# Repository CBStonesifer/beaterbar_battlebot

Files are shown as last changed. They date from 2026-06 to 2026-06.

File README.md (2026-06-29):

# Beater-Bar BattleBot

A 3-pound (beetleweight) combat robot designed and built across the full hardware stack: mechanical CAD, PCB layout, and embedded firmware. The goal was a **reproducible end-to-end build process** — from CAD model to fabricated board to driving firmware — rather than peak performance. V2 will optimize for weight and combat performance.

> A full reflection on the build is on Substack: [Earning Three Minutes in the Ring](https://open.substack.com/pub/carterstonesifer/p/earning-three-minutes-in-the-ring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)

**Skills demonstrated:** Fusion 360 / FDM prototyping · KiCad schematic + layout · custom footprint creation · Gerber fabrication output · ESP32 embedded C · RC PWM decode · LEDC motor PWM · skid-steer mixing

---

## Repo Structure

```
cad/          — 3D-printable chassis, wheels, and weapon (STL + 3MF)
pcb/          — KiCad schematic, layout, custom footprints, and gerbers
firmware/     — Arduino sketch for ESP32 (RC decode + motor mixing)
```

---

## Design Decisions

- **Beater bar weapon** — a relatively simple and proven design with high impact potential in the arena. The main weakness is being flipped; a lower profile in V2 addresses this directly.
- **Unified motor driver (DRV8833)** — the same driver module is used for all three motors (left drive, right drive, weapon). Simplifies the BOM and firmware; the weapon motor runs off its own dedicated DRV8833 instance.
- **Skid-steer drivetrain** — keeps mechanical complexity low while maintaining full mobility. No steering linkage, no Ackermann geometry, just two independently driven wheels.
- **Belt-driven weapon** — the GT2 20T/60T pulley ratio amplifies the motor's output speed to spin the beater bar faster than a direct-drive setup would allow.
- **Unitary printed body** — a single-piece chassis provides structural strength without mechanical interlocks between parts. Drive and weapon geometry were validated as separate prints first, then merged once the layout was confirmed.

---

## Bill of Materials

| # | Component | Part | Qty | Specs | Link |
|---|---|---|-----|---|---|
| 1 | MCU | ESP32 dev board | 1 | Dual-core 32-bit, 240 MHz, 3.3V, WiFi + BT | [Amazon](https://www.amazon.com/dp/B0C9TGJRPH) |
| 2 | Motor driver | DRV8833 | 3 | 1.5 A continuous, 2 A peak | [Amazon](https://www.amazon.com/dp/B0DXF6LZB1) |
| 3 | Buck regulator | LM2596 | 1 | 3–40V in, 1.5–35V adj out | [Amazon](https://www.amazon.com/dp/B0DBVYP91F) |
| 4 | Battery | 2S LiPo | 1 | 7.4V, 2000mAh, T-plug | [Amazon](https://www.amazon.com/dp/B0FCFVWS1K) |
| 5 | RC transmitter + receiver | — | 1 set | PWM out, 2-channel minimum | [Amazon](https://www.amazon.com/dp/B0FJDFJ38M) |
| 6 | Drive motors | 390 brushed | 2 | 6–12V, 6,300 RPM @ 12V, 1A no-load, 2.3mm shaft | [Amazon](https://www.amazon.com/dp/B01M58POHF) |
| 7 | Weapon motor | 550 brushed, 55T | 1 | 7.4V (2S), 36mm dia, 3.17mm shaft | [Amazon](https://www.amazon.com/dp/B0FXG6J3Z9) |
| 8 | Weapon belt drive | GT2 pulley + belt | 1 set | 20T / 60T, 8mm bore, 200mm belt | [Amazon](https://www.amazon.com/dp/B08QZ4365D) |
| 9 | Connectors | JST-XH 3-pin | 10 pairs | 2.54mm pitch, 26AWG, 200mm | [Amazon](https://www.amazon.com/dp/B0D3LVLMP9) |
| 10 | Print filament | PLA-CF 1.75mm | 1 spool | 1kg, carbon-fiber reinforced | [Amazon](https://www.amazon.com/dp/B0D7VV1YC7) |

---

## CAD

**Tool:** Fusion 360 → FDM (PLA-CF)  
**All parts:** `cad/` — available as both `.stl` and `.3mf`

| File | Description |
|---|---|
| `chassis.stl` / `.3mf` | Unitary chassis: electronics bay, drive motor mounts, weapon mount |
| `drive_wheel.stl` / `.3mf` | Drive wheels (print ×2) |
| `weapon_impactor.stl` / `.3mf` | Beater-bar weapon impactor |

Drive and weapon subsystems were first validated as separate prints, then consolidated into a single `chassis` once geometry was confirmed. Total bot target: ≤ 3 lb; drive motors are the dominant mass — body is designed to be as light as possible.

| | |
|---|---|
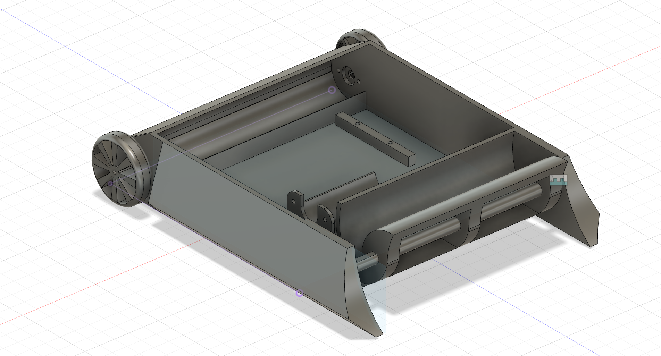
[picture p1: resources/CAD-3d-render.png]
Fusion 360 chassis render
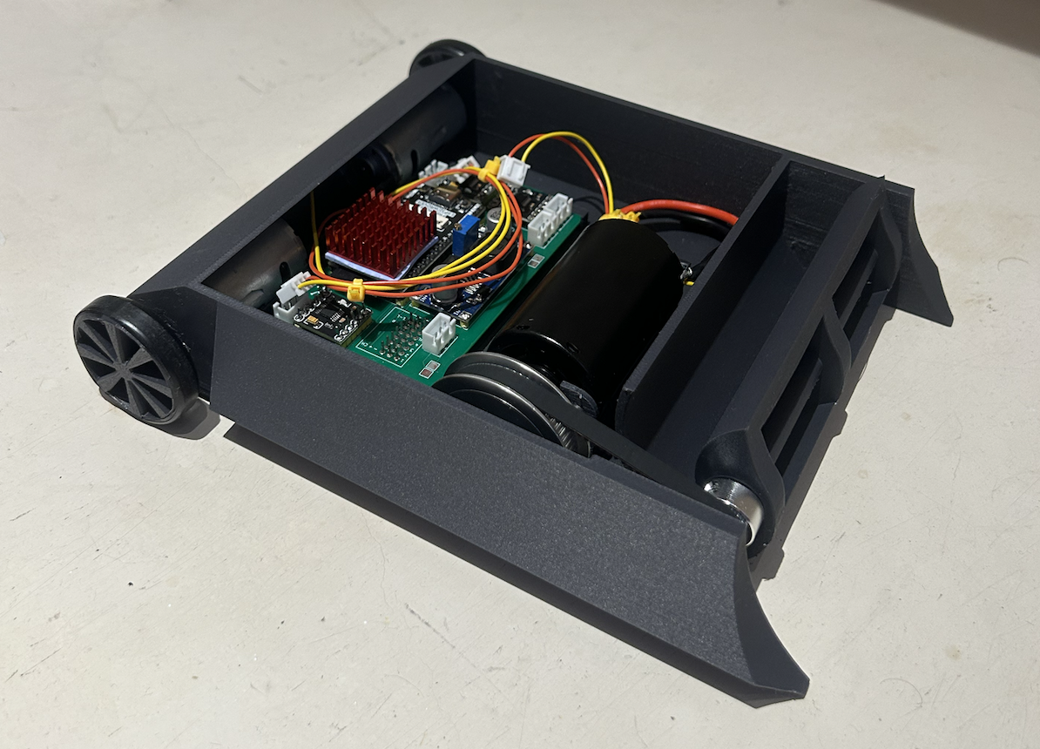
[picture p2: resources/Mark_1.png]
Assembled Mark 1
|  |  |
| *Fusion 360 render — `chassis`* | *Mark 1 assembled — PCB and drive motor installed* |

---

## ECAD

**Tool:** KiCad 7  
**Fabrication output:** `pcb/gerbers/battlebot_gerbers_v1.zip` — ready to send to any fab house

### Files

| File | Purpose |
|---|---|
| `pcb/BattleBot.kicad_sch` | Full schematic |
| `pcb/BattleBot.kicad_pcb` | Board layout |
| `pcb/BattleBot-parts.kicad_sym` | Custom KiCad symbol library |
| `pcb/BattleBot.pretty/` | Custom footprint library (6 footprints) |
| `pcb/gerbers/` | Gerber + drill files |

### Power Architecture

```
LiPo ──→ LM2596 (buck) ──→ 5V ──→ ESP32-WROVER-E
LiPo ──→ DRV8833 (×3) ──→ Drive motors + weapon motor (direct VBAT)
```

### GPIO Pin Assignments

| Signal | ESP32 GPIO |
|---|---|
| RC Steering (PWM in) | 35 |
| RC Throttle (PWM in) | 34 |
| RC Weapon toggle (PWM in) | 18 |
| Left motor IN1 | 25 |
| Left motor IN2 | 26 |
| Right motor IN1 | 27 |
| Right motor IN2 | 14 |
| Weapon motor IN1 | 2 |
| Weapon motor IN2 | 15 |
| UART0 debug | 115200 baud |

### Custom Footprints

All footprints in `pcb/BattleBot.pretty/` were drawn from datasheets:

| Footprint | File |
|---|---|
| ESP32-WROVER-E | `ESP32-WROVER-E.kicad_mod` |
| DRV8833 | `DRV8833.kicad_mod` |
| LM2596 | `LM2596.kicad_mod` |
| RC Receiver | `Receiver.kicad_mod` |
| 3-pin connector | `3Pin-Connector.kicad_mod` |
| Test point pad | `Testpoint-Pad.kicad_mod` |

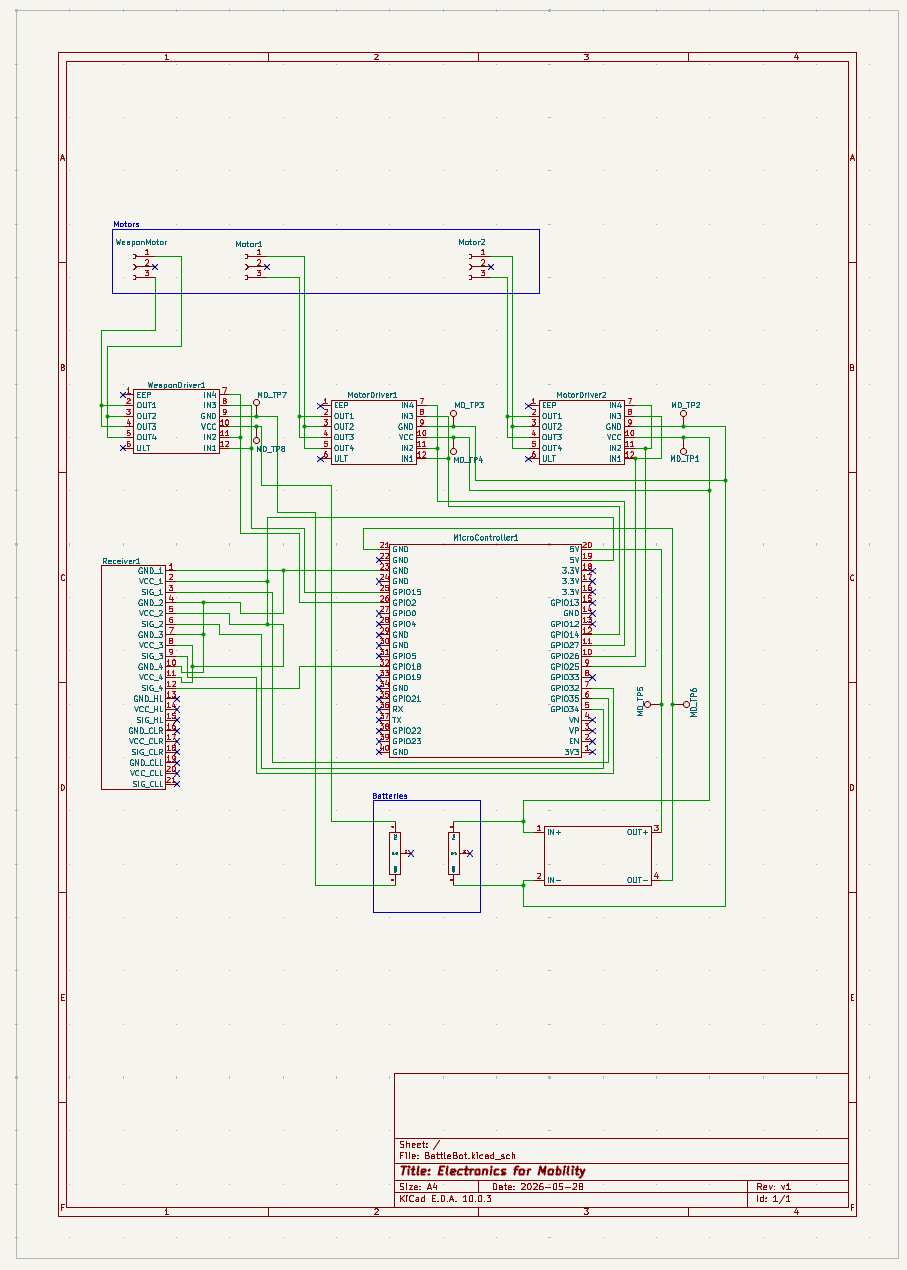
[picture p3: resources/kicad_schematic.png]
KiCad schematic

*Schematic — `BattleBot.kicad_sch`*

| | |
|---|---|
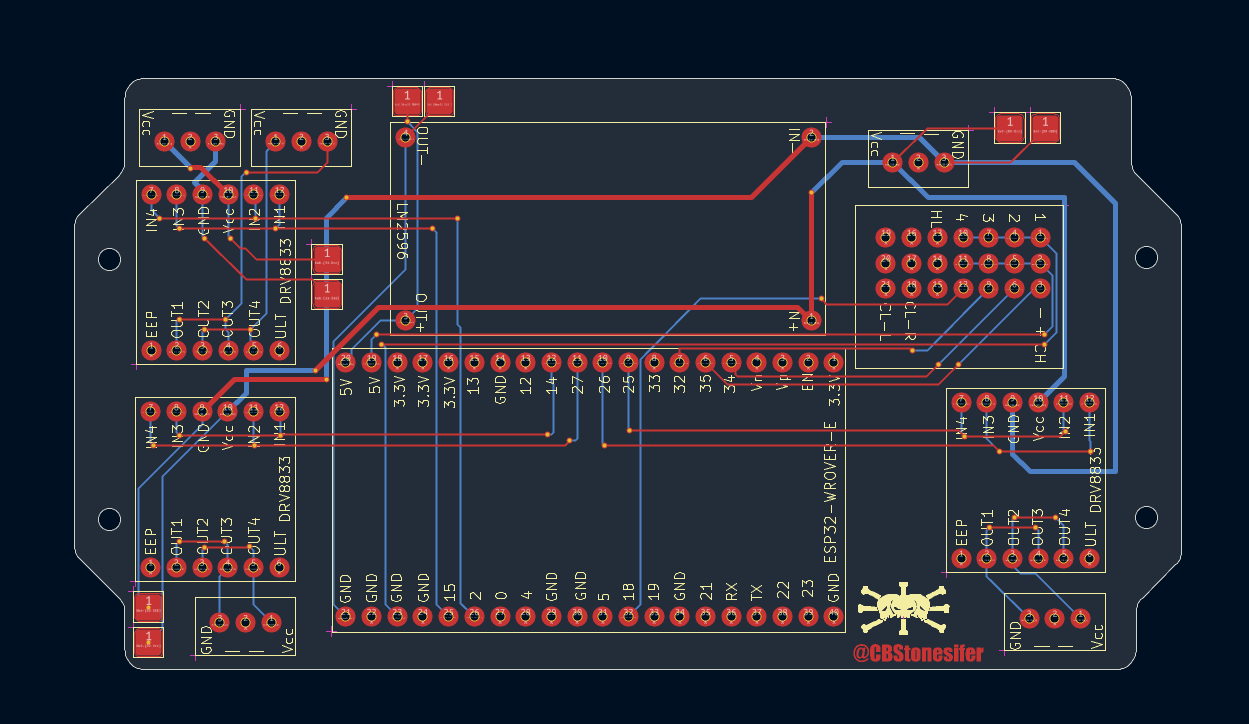
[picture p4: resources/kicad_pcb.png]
KiCad PCB layout
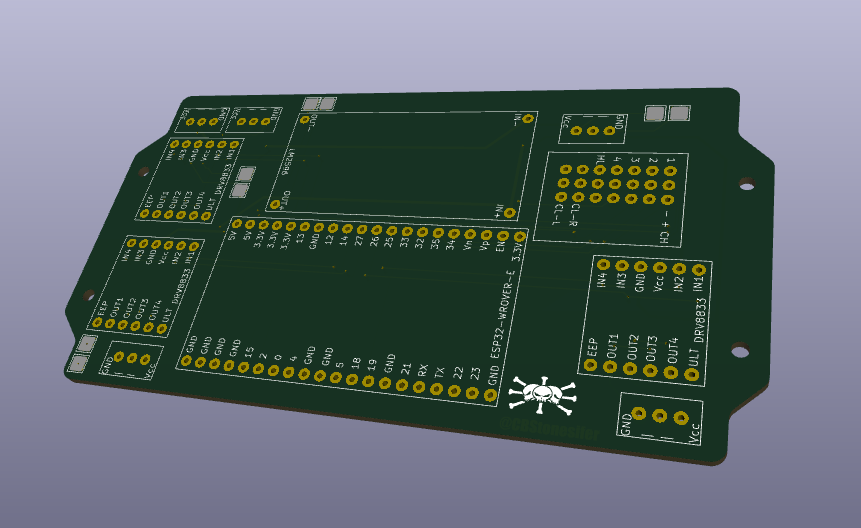
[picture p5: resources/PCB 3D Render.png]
PCB 3D render
|  |  |
| *Layout — `BattleBot.kicad_pcb`* | *KiCad 3D render* |

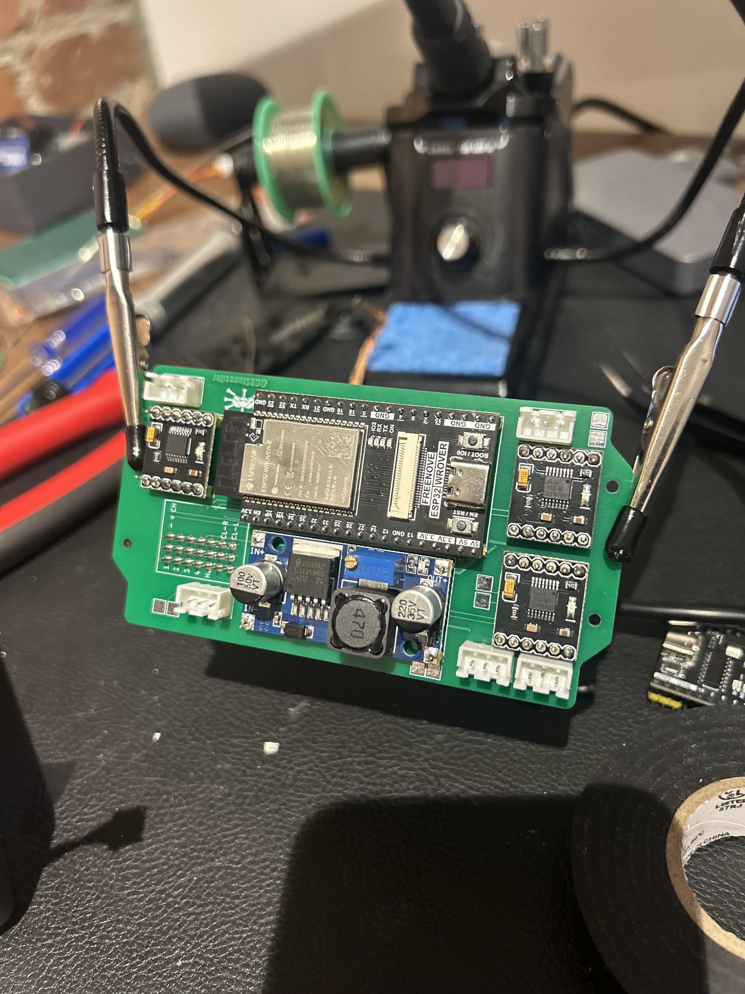
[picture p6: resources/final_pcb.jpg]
Populated PCB

*Fabricated and populated board*

---

## Firmware

**Toolchain:** Arduino IDE + ESP32 board support package  
**Board target:** ESP32 Wrover Module  
**Sketch:** `firmware/signal_driver/signal_driver.ino`

### Control Loop

```
loop()
  ├── pulseIn GPIO 35/34/18  — read steering, throttle, weapon (25ms timeout each)
  ├── failsafe check         — any invalid/missing pulse → stopAll() and skip frame
  ├── steeringFromPulse()    — map to [-100, 100] → deadband
  ├── throttleFromPulse()    — map to [-100, 100] → deadband
  ├── mixAndDrive()          — skid-steer mix → setMotor() → LEDC PWM duty
  └── setWeapon()            — full speed on WEAPON_IN1 when pulse > 1500 µs
```

> **Failsafe:** `pulseIn` returns 0 on timeout, and a valid RC frame sits ~1000–2000 µs. Any pulse outside the 900–2100 µs band is treated as link loss — all drive and weapon output is cut for that loop. Without this guard a lost signal maps to full reverse, so the bot drives off on its own when the transmitter drops.

### Motor Mixing

- **Straight:** `left = right = throttle`
- **Driving turn:** inner wheel = `throttle × (TURN_MIX_RATIO / 100)`
- **Spin-in-place:** `left = +steering`, `right = −steering`

### Calibration Constants

| Constant | V1 Value | Purpose |
|---|---|---|
| `STEERING_MIN` | 965 µs | Min receiver pulse |
| `STEERING_MAX` | 1882 µs | Max receiver pulse |
| `THROTTLE_MIN` | 1055 µs | Min throttle pulse |
| `THROTTLE_IDLE` | 1565 µs | Neutral position |
| `THROTTLE_MAX` | 2000 µs | Max throttle pulse |
| `DEADBAND` | 5 | Noise rejection around neutral |
| `TURN_MIX_RATIO` | 50 | Inner-wheel scaling (0–100) |
| `PWM_FREQ` | 20,000 Hz | LEDC motor PWM frequency |
| `PWM_RES` | 8-bit | Duty cycle range (0–255) |

> These constants are radio-specific. Re-measure pulse widths for your transmitter before first drive.

### Flash Instructions

1. Install ESP32 board support in Arduino IDE
2. Open `firmware/signal_driver/signal_driver.ino`
3. Select **ESP32 Wrover Module**, set the correct COM port
4. Update calibration constants for your RC radio
5. Upload

---

## Testing & Validation

The bot was driven under full battery power with all systems operating independently:

- **Drive** — successfully accelerated, turned, and reversed at varying speeds under RC control.
- **Weapon** — spun up to full speed and was toggled on and off from the transmitter.
- **Carpet performance** — struggled on carpet. The wheels lacked grip, and the design relies on the body sliding along the ground to stay low against opponents — which doesn't work well on high-friction surfaces.
- **Battery connector** — the 3-pin plugs do not physically prevent reverse polarity insertion. Connecting the battery backwards is easy to do and will damage the board.

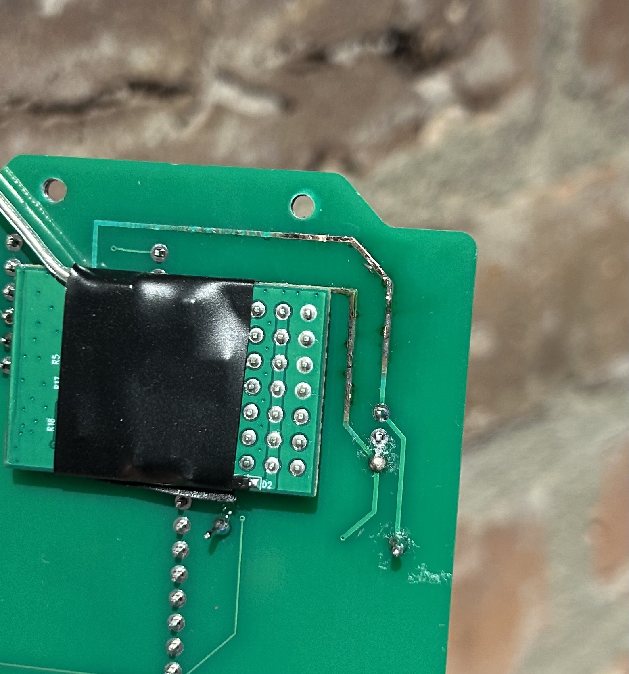
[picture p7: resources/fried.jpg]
Fried ESP32 from reverse polarity

<br><em>ESP32 after a flipping power contacts</em>

---

## Known Issues & Further Improvements (V2)

- **Chassis Side Overhangs** — the overhangs on the side were quickly added to thicken the width of the walls to strengthen the bot, and for style. They provide a grip for another bot to easily flip the vehicle. The next design should minimize the gap between the side edges and the ground.
- **Hard Power Cut-Off** — as per NHRL rules, the bot requires a quick physical power disconnect to disable movement and weapon systems, not just a code deactivation.
- **Reverse-polarity protection** — V1 fried a board because the 3-pin power plug can be inserted backwards. V2 should add a series Schottky / P-channel MOSFET ideal-diode at the battery input *and* a keyed/slotted connector so the battery physically can't seat the wrong way. The board itself is cheap and easily reproducible from the gerbers, so losing one to this wasn't costly — but it's a trivial thing to design out.
- **Undersized motor drivers** — the DRV8833 is rated 1.5 A continuous / 2 A peak, but the 390 drive motors stall around 5–7 A and the 550 weapon motor well above that. Under real load the part is pushed past its peak, where it current-limits or fails. V2 should size the H-bridge to *stall* current, not no-load current, and add a firmware soft-start ramp so the weapon spins up gradually instead of slamming to full duty and drawing a large inrush spike. The broader lesson: parts that work together aren't necessarily matched on performance — each one needs headroom for the worst case the system will actually see.
- **Hardened weapon impactor** — machine or print in PETG/nylon/polycarbonate; evaluate a metal impactor for the beater bar.
- **Weight optimization** — the current design is 2.76 lbs, which leaves room to upgrade/add additional parts (i.e. the weapon material should be metal).
- **Optimize print settings** — a final print with more granular layer heights and higher infill will strengthen the hull.
- **A Roof** — the top of the bot needs a solid roof that could also act as a battery retainer. Batteries are currently loose within the chassis.
- **Sweet Paint Job** — the bot needs some decals and a layer of spray paint to make it look more threatening.
- **Wheel Grips and Covers** — the wheels are exposed and use electrical tape for grip. They must be better protected, as immobility is an immediate loss in the arena. A set of proper tires would help with mobility, and the front shovel can catch on uneven surfaces.
- **Beater Bar orientation is reversed** — the edge of the beater bar faces inward, counter to the direction the bar spins. Opposing robots are hit with the blunt edge of the weapon rather than the sharp, scraping side that should brush close to the ground.
- **Blocking RC read (`pulseIn`)** — the firmware reads each RC channel sequentially using `pulseIn()`, which blocks for up to ~25ms per channel, so a full loop can take ~75ms. Signal loss is now handled (an invalid/missing pulse disarms all motors), but the read is still blocking. V2 should use hardware interrupts or RTOS tasks to read channels concurrently.

---

## Tools Required

- **3D printer** — Bambu A1 (or equivalent FDM printer capable of PLA-CF)
- **Soldering iron** — flux is mandatory; makes the joints significantly cleaner and easier
- **Wire stripper**
- **Extra header pins**
- **Assorted screws and a screwdriver**

---

## Status

| Version | Status | Focus |
|---|---|---|
| V1 | Complete | Cost-optimized, full-stack process established |
| V2 | Planned | Weight/performance, hardened materials, active fault handling |

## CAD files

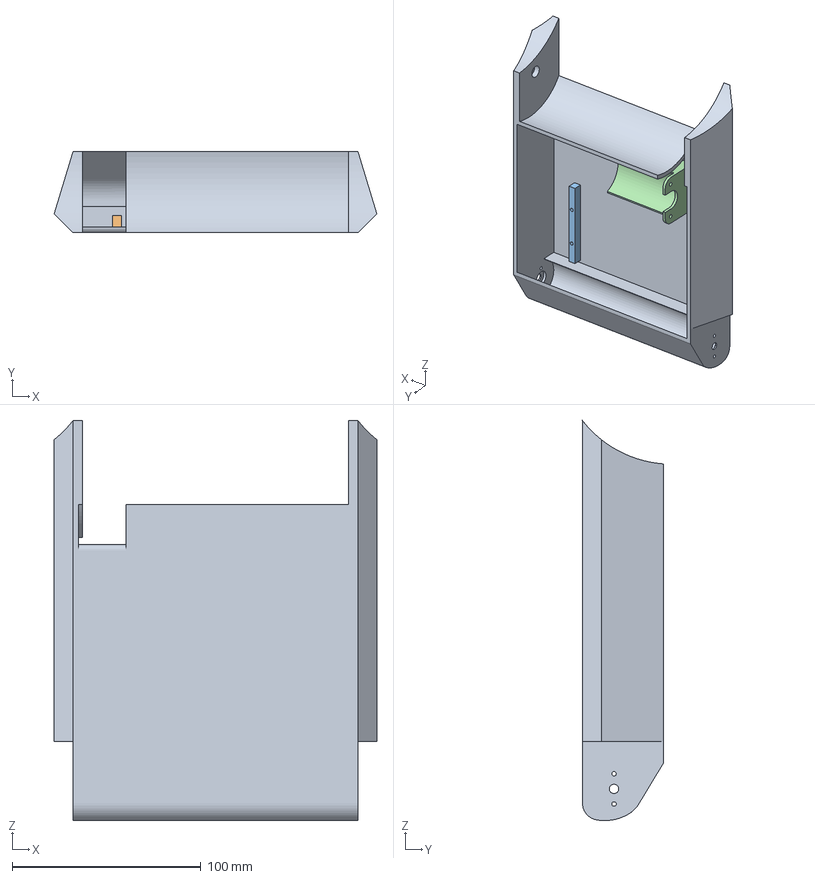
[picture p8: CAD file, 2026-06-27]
cad/chassis.3mf
171.0 x 43.0 x 212.0 mm

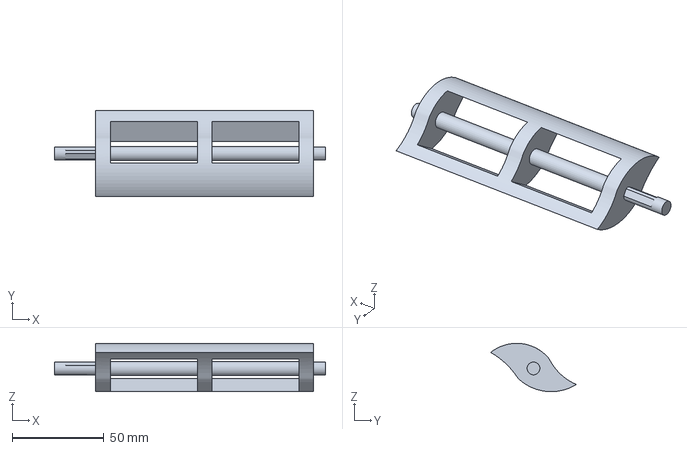
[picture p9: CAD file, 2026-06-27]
cad/weapon_impactor.3mf
148.0 x 46.8 x 26.3 mm

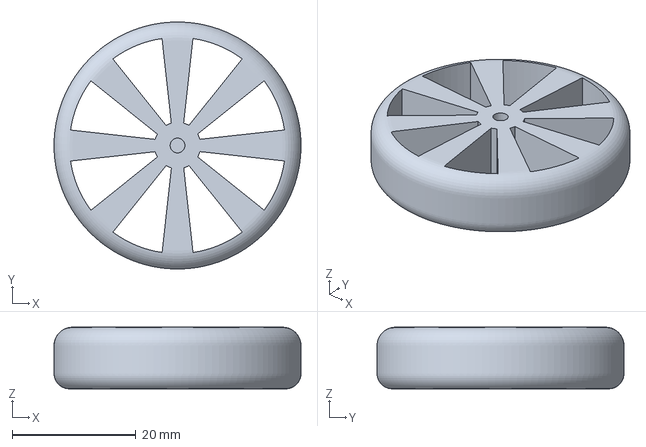
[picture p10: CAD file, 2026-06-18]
cad/drive_wheel.3mf
40.0 x 40.0 x 10.0 mm

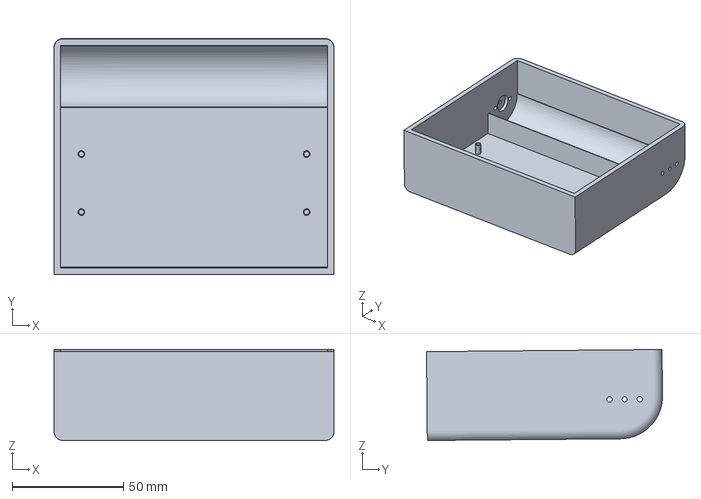
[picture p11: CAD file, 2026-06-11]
cad/haul_v1.3mf
126.0 x 106.2 x 41.0 mm

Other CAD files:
cad/chassis.stl
cad/drive_wheel.stl
cad/weapon_impactor.stl

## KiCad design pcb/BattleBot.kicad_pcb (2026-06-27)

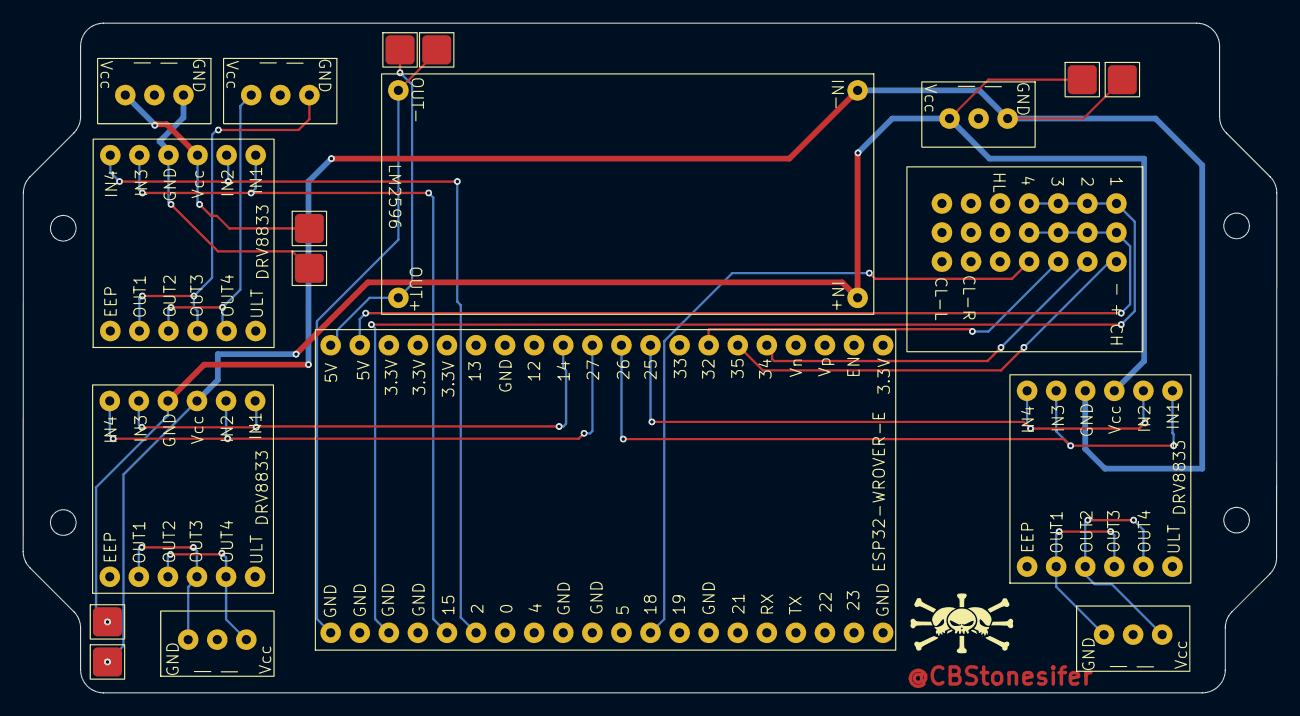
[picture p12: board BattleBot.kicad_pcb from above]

Board: 4 copper layers, 109.5 x 58.5 mm, 19 parts (0 on the bottom side), 24 nets.

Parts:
B1: 3Pin-Connector
B2: Vcc; 3Pin-Connector
Buck1: LM2596
J1: WeaponMotor; 3Pin-Connector
J2: Motor1; 3Pin-Connector
J3: Motor2; 3Pin-Connector
MD_TP1, MD_TP2, MD_TP3, MD_TP4, MD_TP5, MD_TP6, MD_TP7, MD_TP8: Motor Driver Test Point 1; Testpoint-Pad
MicroController1: ESP32-WROVER-E
MotorDriver1, MotorDriver2: DRV8833
Receiver1: Receiver
WeaponDriver1: DRV8833

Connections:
unnamed: B1.3 (GND), MD_TP7.1 (1_1), WeaponDriver1.9 (GND)
unnamed: B1.1 (Vcc), MD_TP8.1 (1_1), WeaponDriver1.10 (VCC)
unnamed: B2.3 (GND), Buck1.2 (IN-), MD_TP2.1 (1_1), MD_TP3.1 (1_1), MotorDriver1.9 (GND), MotorDriver2.9 (GND)
unnamed: B2.1 (Vcc), Buck1.1 (IN+), MD_TP1.1 (1_1), MD_TP4.1 (1_1), MotorDriver1.10 (VCC), MotorDriver2.10 (VCC)
unnamed: Buck1.3 (OUT+), MD_TP5.1 (1_1), MicroController1.20 (5V)
unnamed: Buck1.4 (OUT-), MD_TP6.1 (1_1), MicroController1.21 (GND)
unnamed: J1.1, WeaponDriver1.3 (OUT2), WeaponDriver1.5 (OUT4)
unnamed: J1.3, WeaponDriver1.2 (OUT1), WeaponDriver1.4 (OUT3)
unnamed: J2.1, MotorDriver1.3 (OUT2), MotorDriver1.5 (OUT4)
unnamed: J2.3, MotorDriver1.2 (OUT1), MotorDriver1.4 (OUT3)
unnamed: J3.1, MotorDriver2.3 (OUT2), MotorDriver2.5 (OUT4)
unnamed: J3.3, MotorDriver2.2 (OUT1), MotorDriver2.4 (OUT3)
unnamed: MicroController1.26 (GPIO2), WeaponDriver1.7 (IN4), WeaponDriver1.11 (IN2)
unnamed: MicroController1.12 (GPIO14), MotorDriver1.8 (IN3), MotorDriver1.12 (IN1)
unnamed: MicroController1.25 (GPIO15), WeaponDriver1.8 (IN3), WeaponDriver1.12 (IN1)
unnamed: MicroController1.32 (GPIO18), Receiver1.12 (SIG_4)
unnamed: MicroController1.9 (GPIO25), MotorDriver2.7 (IN4), MotorDriver2.11 (IN2)
unnamed: MicroController1.10 (GPIO26), MotorDriver2.8 (IN3), MotorDriver2.12 (IN1)
unnamed: MicroController1.11 (GPIO27), MotorDriver1.7 (IN4), MotorDriver1.11 (IN2)
unnamed: MicroController1.7 (GPIO32), Receiver1.9 (SIG_3)
unnamed: MicroController1.5 (GPIO34), Receiver1.6 (SIG_2)
unnamed: MicroController1.6 (GPIO35), Receiver1.3 (SIG_1)
unnamed: MicroController1.23 (GND), Receiver1.1 (GND_1), Receiver1.4 (GND_2), Receiver1.7 (GND_3), Receiver1.10 (GND_4)
unnamed: MicroController1.19 (5V), Receiver1.2 (VCC_1), Receiver1.5 (VCC_2), Receiver1.8 (VCC_3), Receiver1.11 (VCC_4)

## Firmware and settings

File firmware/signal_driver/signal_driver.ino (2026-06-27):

// ── Pins ──────────────────────────────────────────────────────────────────
const int STEERING_PIN = 35;
const int THROTTLE_PIN = 34;
const int WEAPON_PIN   = 18;

const int MOTOR_L_IN1  = 25;
const int MOTOR_L_IN2  = 26;
const int MOTOR_R_IN1  = 27;
const int MOTOR_R_IN2  = 14;
const int WEAPON_IN1   = 2;
const int WEAPON_IN2   = 15;

// ── PWM config ────────────────────────────────────────────────────────────
const int PWM_FREQ = 20000;
const int PWM_RES  = 8;

// ── Receiver calibration (µs) ─────────────────────────────────────────────
const int STEERING_MIN  = 965;
const int STEERING_MAX  = 1882;

const int THROTTLE_MIN  = 1055;
const int THROTTLE_IDLE = 1565;
const int THROTTLE_MAX  = 2000;

// ── Tuning ────────────────────────────────────────────────────────────────
const int DEADBAND         = 5;
const int TURN_MIX_RATIO   = 50;
const int WEAPON_THRESHOLD = 1500;

// ── Failsafe ──────────────────────────────────────────────────────────────
// pulseIn returns 0 on timeout (no signal). A valid RC frame sits ~1000-2000µs,
// so anything outside this band is link loss or a glitch -> stop everything.
const int PULSE_TIMEOUT = 25000;
const int PULSE_MIN_OK  = 900;
const int PULSE_MAX_OK  = 2100;

// ─────────────────────────────────────────────────────────────────────────
void setup() {
  Serial.begin(115200);
  delay(500);
  Serial.println("\n=== BATTLEBOT STARTING ===");

  pinMode(STEERING_PIN, INPUT);
  pinMode(THROTTLE_PIN, INPUT);
  pinMode(WEAPON_PIN,   INPUT);

  ledcAttachChannel(MOTOR_L_IN1, PWM_FREQ, PWM_RES, 0);
  ledcAttachChannel(MOTOR_L_IN2, PWM_FREQ, PWM_RES, 1);
  ledcAttachChannel(MOTOR_R_IN1, PWM_FREQ, PWM_RES, 2);
  ledcAttachChannel(MOTOR_R_IN2, PWM_FREQ, PWM_RES, 3);
  ledcAttachChannel(WEAPON_IN1,  PWM_FREQ, PWM_RES, 4);
  ledcAttachChannel(WEAPON_IN2,  PWM_FREQ, PWM_RES, 5);

  stopAll();
  Serial.println("Setup complete.");
}

// ── True only for a plausible RC pulse; false on timeout/glitch ───────────
bool validPulse(int pulse) {
  return pulse >= PULSE_MIN_OK && pulse <= PULSE_MAX_OK;
}

// ── Cut all drive and weapon output ───────────────────────────────────────
void stopAll() {
  ledcWrite(MOTOR_L_IN1, 0);
  ledcWrite(MOTOR_L_IN2, 0);
  ledcWrite(MOTOR_R_IN1, 0);
  ledcWrite(MOTOR_R_IN2, 0);
  ledcWrite(WEAPON_IN1,  0);
  ledcWrite(WEAPON_IN2,  0);
}

// ── Write a signed speed (-100..100) to one motor ─────────────────────────
void setMotor(int pinA, int pinB, int speed) {
  speed = constrain(speed, -100, 100);
  int duty = map(abs(speed), 0, 100, 0, 255);
  if (speed > 0) {
    ledcWrite(pinA, duty);
    ledcWrite(pinB, 0);
  } else if (speed < 0) {
    ledcWrite(pinA, 0);
    ledcWrite(pinB, duty);
  } else {
    ledcWrite(pinA, 0);
    ledcWrite(pinB, 0);
  }
}

// ── Deadband ──────────────────────────────────────────────────────────────
int applyDeadband(int value) {
  return abs(value) <= DEADBAND ? 0 : value;
}

// ── Convert a validated steering pulse to -100 (left) .. +100 (right) ──────
int steeringFromPulse(int pulse) {
  int steering = map(pulse, STEERING_MIN, STEERING_MAX, -100, 100);
  return applyDeadband(constrain(steering, -100, 100));
}

// ── Convert a validated throttle pulse to -100 (rev) .. +100 (fwd) ─────────
int throttleFromPulse(int pulse) {
  int throttle;
  if (pulse >= THROTTLE_IDLE) {
    throttle = map(pulse, THROTTLE_IDLE, THROTTLE_MAX, 0, 100);
  } else {
    throttle = map(pulse, THROTTLE_MIN, THROTTLE_IDLE, -100, 0);
  }
  return applyDeadband(constrain(throttle, -100, 100));
}

// ── Weapon toggle ─────────────────────────────────────────────────────────
void setWeapon(bool on) {
  ledcWrite(WEAPON_IN1, on ? 255 : 0);
  ledcWrite(WEAPON_IN2, 0);
}

// ── Motor mixing ──────────────────────────────────────────────────────────
void mixAndDrive(int throttle, int steering) {
  int leftSpeed, rightSpeed;

  if (throttle == 0) {
    leftSpeed  =  steering;
    rightSpeed = -steering;
  } else {
    int inner = (throttle * TURN_MIX_RATIO) / 100;
    if (steering > 0) {
      leftSpeed  = throttle;
      rightSpeed = inner;
    } else if (steering < 0) {
      leftSpeed  = inner;
      rightSpeed = throttle;
    } else {
      leftSpeed  = throttle;
      rightSpeed = throttle;
    }
  }

  setMotor(MOTOR_L_IN1, MOTOR_L_IN2, leftSpeed);
  setMotor(MOTOR_R_IN1, MOTOR_R_IN2, rightSpeed);
}

// ─────────────────────────────────────────────────────────────────────────
void loop() {
  int steeringPulse = pulseIn(STEERING_PIN, HIGH, PULSE_TIMEOUT);
  int throttlePulse = pulseIn(THROTTLE_PIN, HIGH, PULSE_TIMEOUT);
  int weaponPulse   = pulseIn(WEAPON_PIN,   HIGH, PULSE_TIMEOUT);

  // Failsafe: drive disarms unless both steering and throttle are live.
  if (!validPulse(steeringPulse) || !validPulse(throttlePulse)) {
    stopAll();
    Serial.println("** SIGNAL LOST -- MOTORS DISABLED **");
    delay(20);
    return;
  }

  int  steering = steeringFromPulse(steeringPulse);
  int  throttle = throttleFromPulse(throttlePulse);
  bool weaponOn = validPulse(weaponPulse) && weaponPulse > WEAPON_THRESHOLD;

  mixAndDrive(throttle, steering);
  setWeapon(weaponOn);

  Serial.print("ST: ");    Serial.print(steering);
  Serial.print("  TH: ");  Serial.print(throttle);
  Serial.print("  WPN: "); Serial.println(weaponOn ? "ON" : "OFF");

  delay(20);
}

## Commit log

2026-06-11 clean up files
    [DRV8333-shape.3mf, DRV8333-shape.step, boardv1.step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]
2026-06-18 mark 1
    [BeaterBar_v2.f3d, BeaterBar_v2.stl, Wheel.3mf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]
2026-06-27 image insert
